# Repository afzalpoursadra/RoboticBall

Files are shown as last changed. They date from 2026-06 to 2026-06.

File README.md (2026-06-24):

# Robotic Ball

An open-source robotic ball platform.

---

## Overview

Robotic Ball is a compact robotics platform that integrates custom mechanical design, embedded electronics, firmware, and a mobile application.
The repository also includes the Gyrobit control UI and release workflow for desktop and Android builds.

The project was developed as a multidisciplinary engineering project involving:

* Mobile Application Development
* Mechanical Design
* PCB Design
* Embedded Programming

---

## Assembly Animation

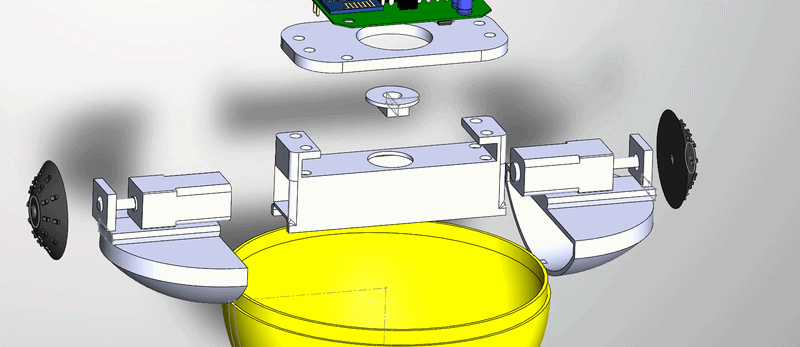
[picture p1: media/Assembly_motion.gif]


---

## Control UI

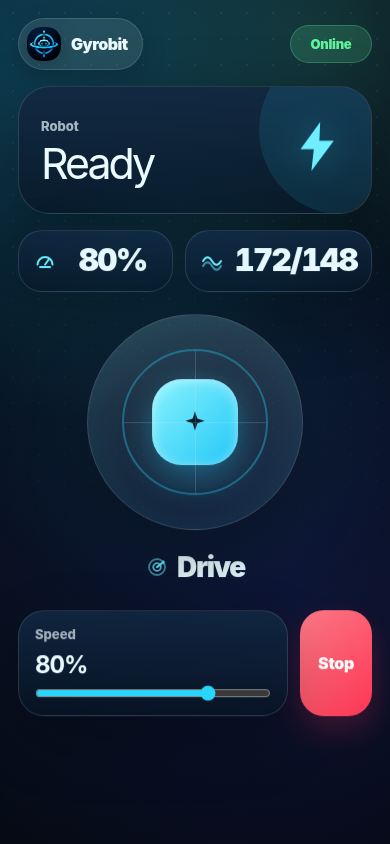
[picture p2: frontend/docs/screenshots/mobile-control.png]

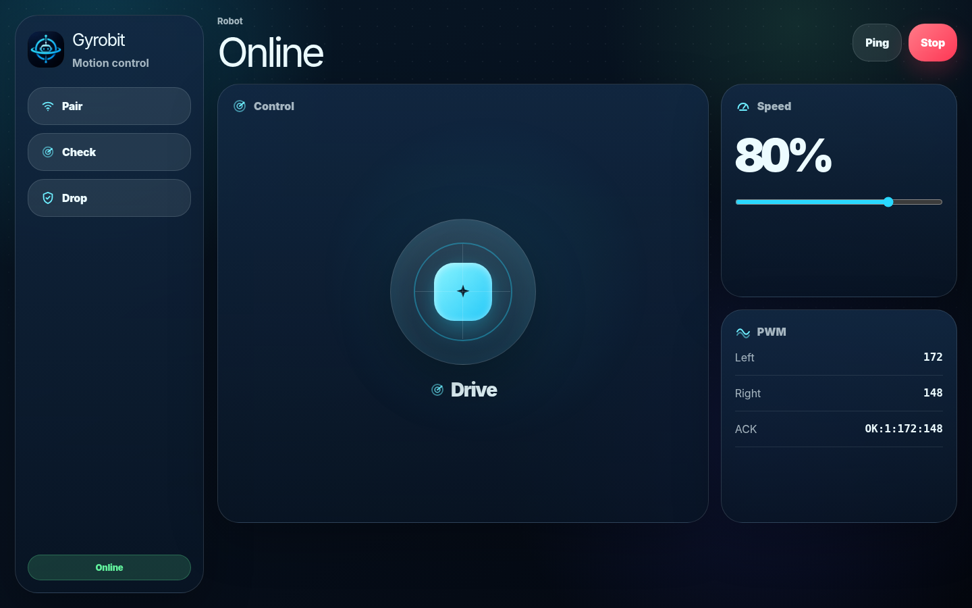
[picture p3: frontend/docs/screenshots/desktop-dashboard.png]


---

### Final Assembly

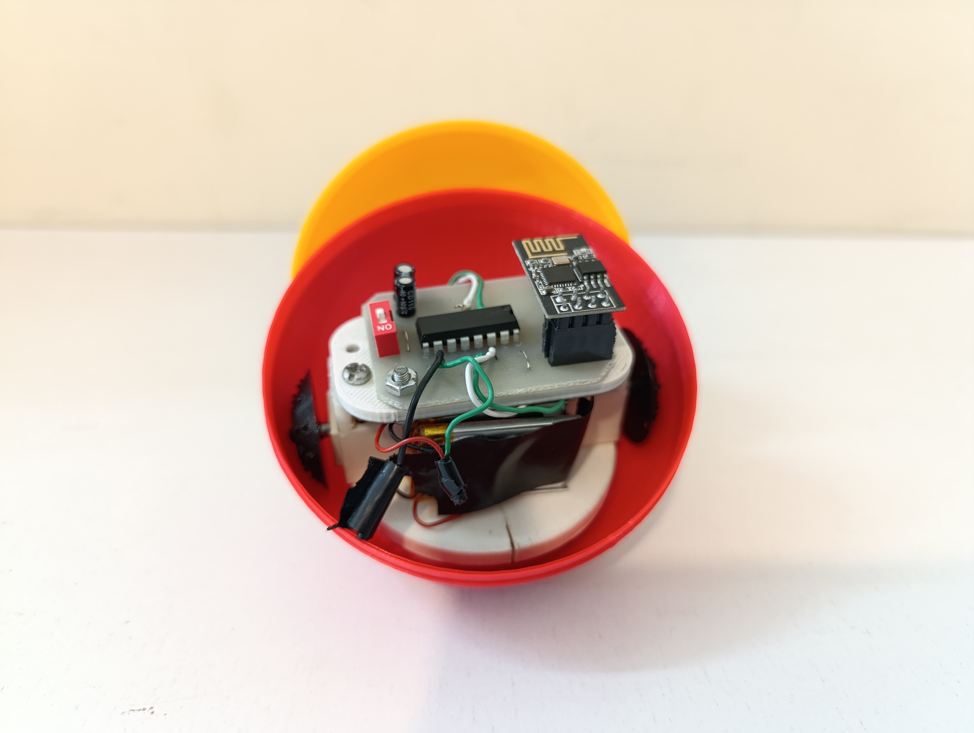
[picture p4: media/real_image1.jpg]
 
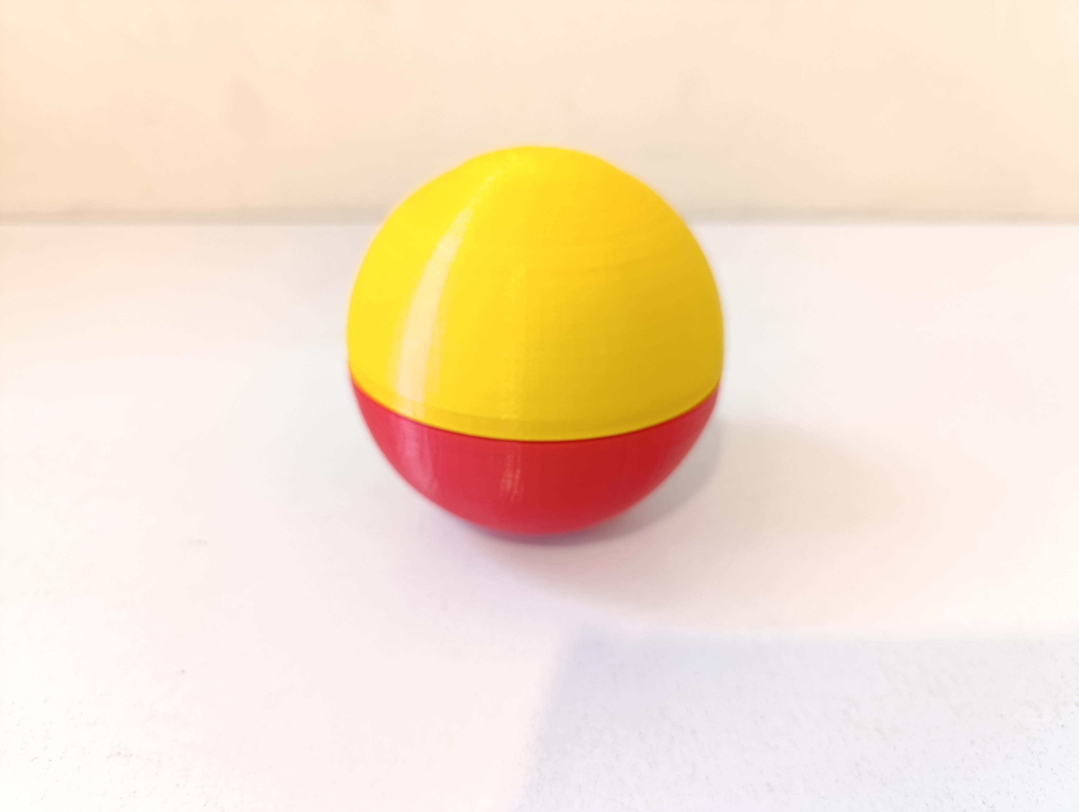
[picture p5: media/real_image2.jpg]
 

---
## Assembly tips

Parts such as the cap and motor holder should be glued together using adhesive.

To charge the batteries, the 2S BMS should be externally attached to the main body.

Then you're ready to go.

---

## License

This project is released under the MIT License.

See the LICENSE file for details.

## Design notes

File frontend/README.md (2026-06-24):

# Gyrobit

Minimal Tauri robot controller for ESP8266 SoftAP robots.

## Preview

### Motion

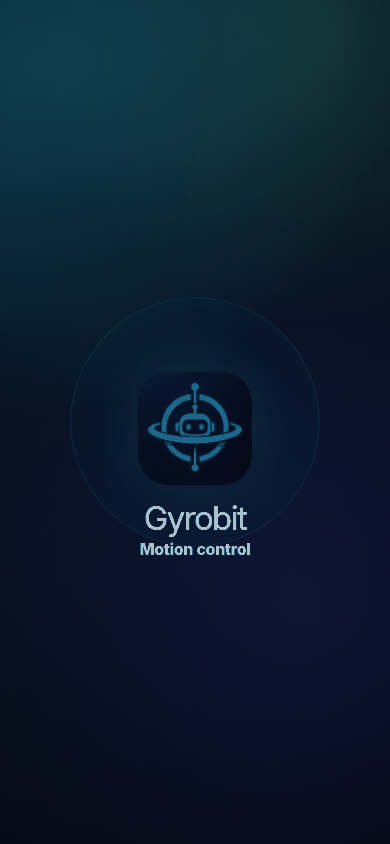
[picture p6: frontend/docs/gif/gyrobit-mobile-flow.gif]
Gyrobit mobile flow


### Pair sheet

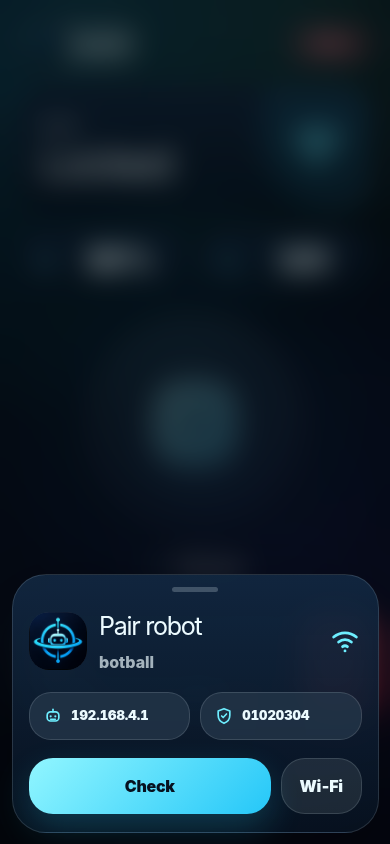
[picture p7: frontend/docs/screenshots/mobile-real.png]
Gyrobit mobile pair


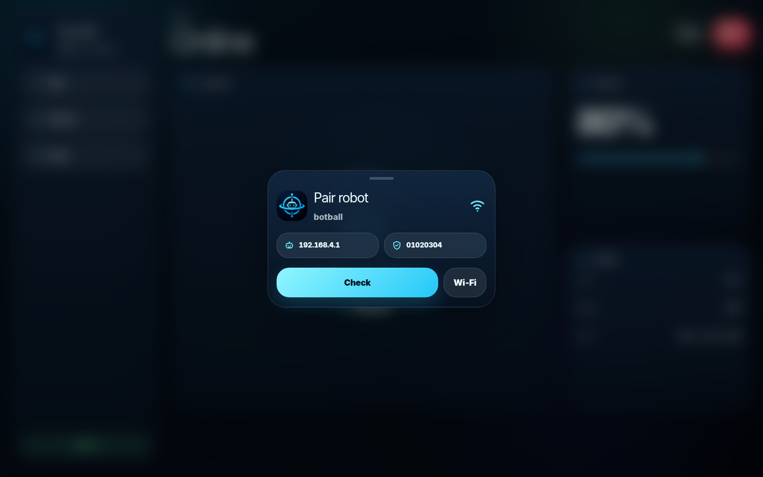
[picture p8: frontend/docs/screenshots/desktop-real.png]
Gyrobit desktop pair


### Control UI

Gyrobit mobile control

Gyrobit desktop dashboard

## Run

```bash
npm install
npm run tauri:dev
```

## Build

```bash
npm run build
npm run tauri:build
```

## Robot link

```txt
SSID: botball
PASS: 01020304
UDP: 192.168.4.1:4210
Payload: J,throttle,steer,speedLimit
ACK: OK:cmd:leftPwm:rightPwm
```

## Features
- Mobile: splash, pair sheet, rounded joystick control.
- Desktop: left panel, dashboard, telemetry cards.
- Wi‑Fi is user-managed; app checks robot by UDP ACK.
- Control payload: `J,throttle,steer,speedLimit`.
- Locked controls until ACK; emergency stop sends stop.
- Firmware: PWM speed, soft turns, failsafe, ACK.

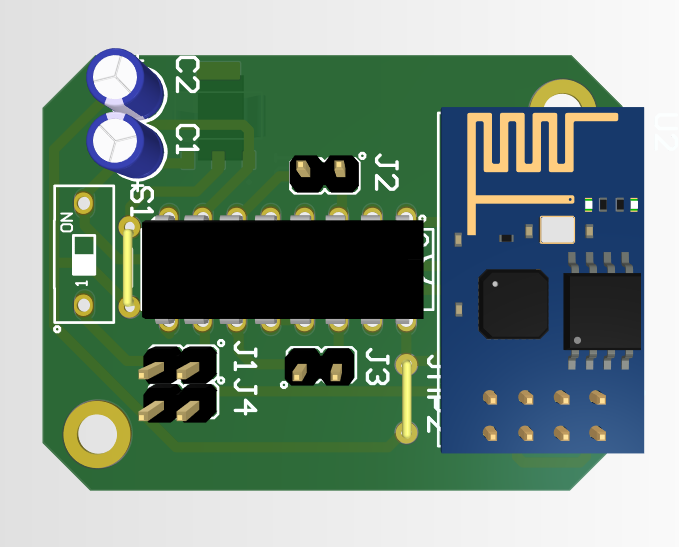
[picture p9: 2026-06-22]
media/PCB.png

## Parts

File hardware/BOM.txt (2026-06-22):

Esp8266_01                      1x

Type of TTL like "CP2102"       1x

l293D IC                        1x

Cap 10uf 25v 4mm                2x

AMS1117-3.3 Smd                 1x 

Bolt M3 10mm                    6x

Nut M3                          2x

DIP switch 1 position           1x

Resistor 4.7k                   2x

wire                           

Header 2*4 used for ESP8266_01  1x

BMS 2S                          1x

Motor N20                       2x

402030 Battery                  2x

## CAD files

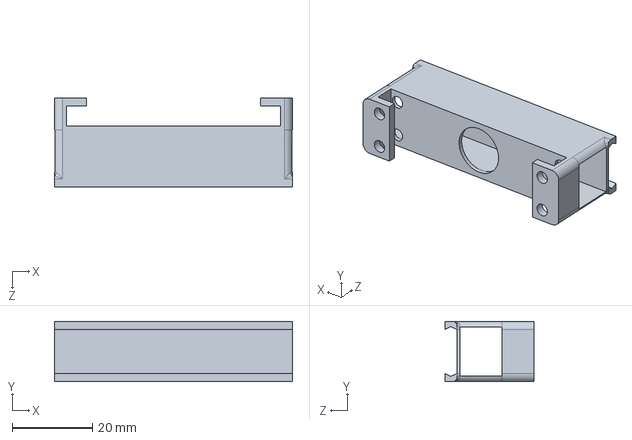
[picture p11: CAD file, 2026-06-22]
mechanical/solidworks/Body_main.SLDPRT
59.4 x 15.0 x 22.3 mm

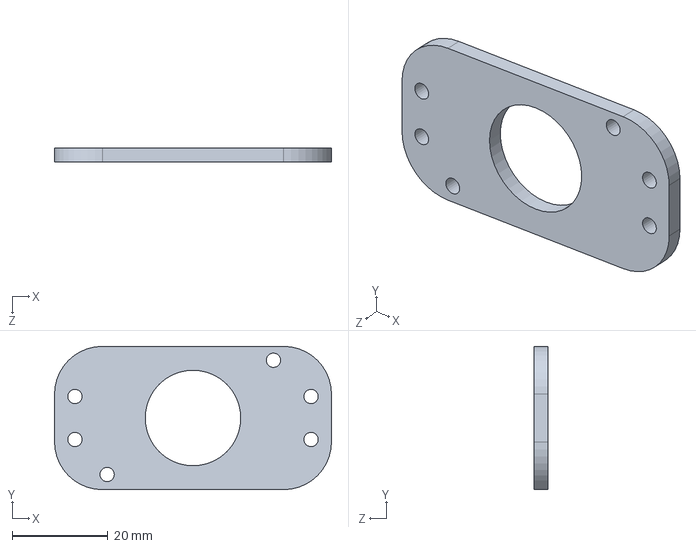
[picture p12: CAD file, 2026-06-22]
mechanical/solidworks/pcb_holder.SLDPRT
58.0 x 30.0 x 3.00 mm

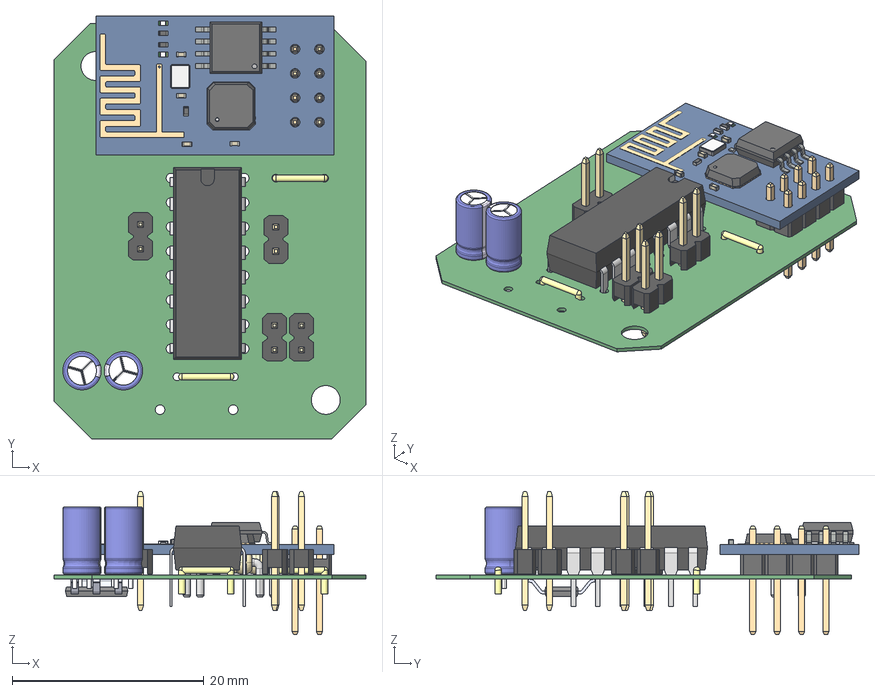
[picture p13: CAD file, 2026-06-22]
mechanical/solidworks/Step_pcb/PCB1.step
32.5 x 44.1 x 14.9 mm
pin_header_aw140-eg-g02a x 4
Resistor Zero x 2
CircuitWorks-DIP 16 IC
User Library-Wi07C
User Library-Cap electrolitic radial 4x7_Case x 2
User Library-Cap electrolitic radial 4x7_Minus x 2
User Library-Cap electrolitic radial 4x7_Top x 2
User Library-Cap electrolitic radial 4x7_Pins x 2
User Library-Cap electrolitic radial 4x7_Bottom x 2

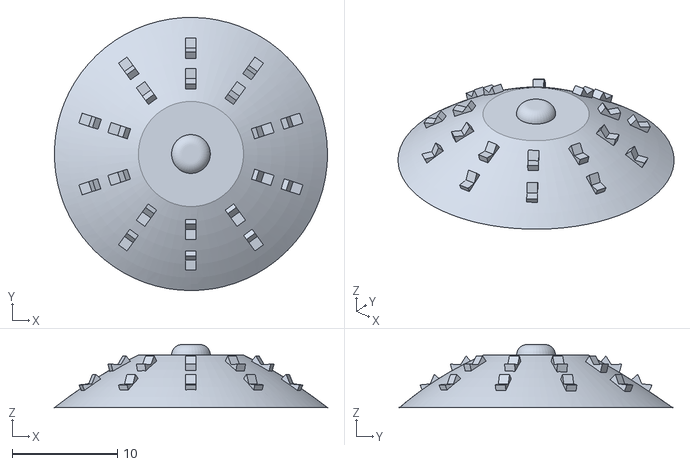
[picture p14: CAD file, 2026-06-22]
mechanical/stl/wheel.STL
26.0 x 26.0 x 6.00

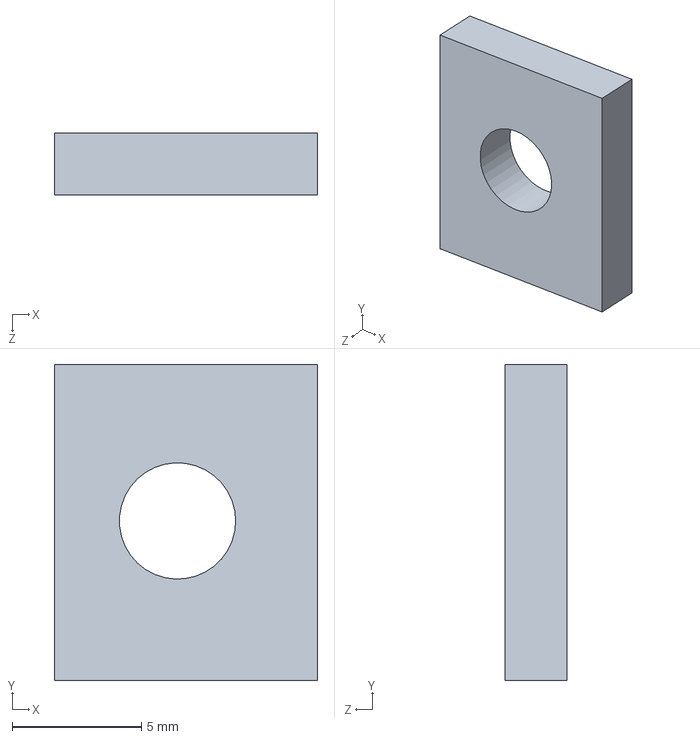
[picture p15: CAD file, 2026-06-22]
mechanical/solidworks/motor_holder_2.SLDPRT
10.2 x 12.2 x 2.40 mm

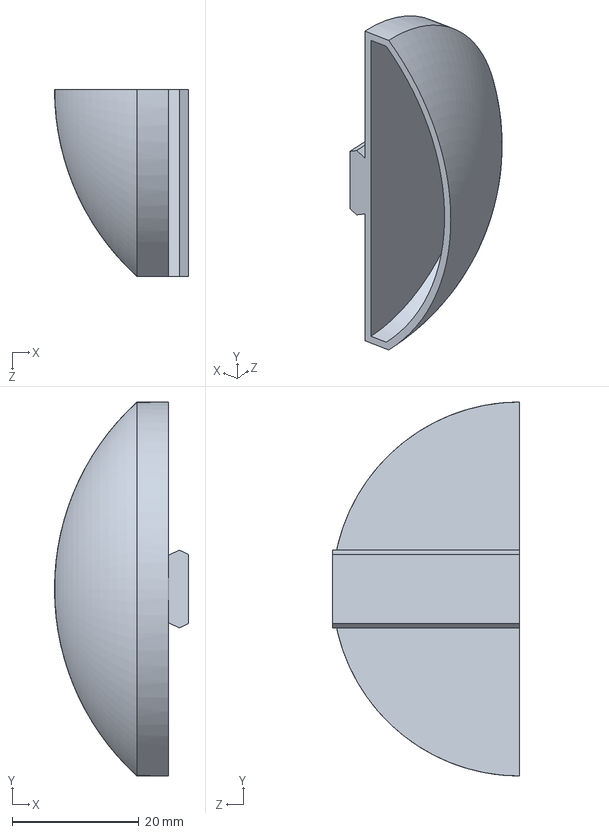
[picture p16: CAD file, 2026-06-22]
mechanical/solidworks/anchor_p2.SLDPRT
21.1 x 59.0 x 29.5 mm

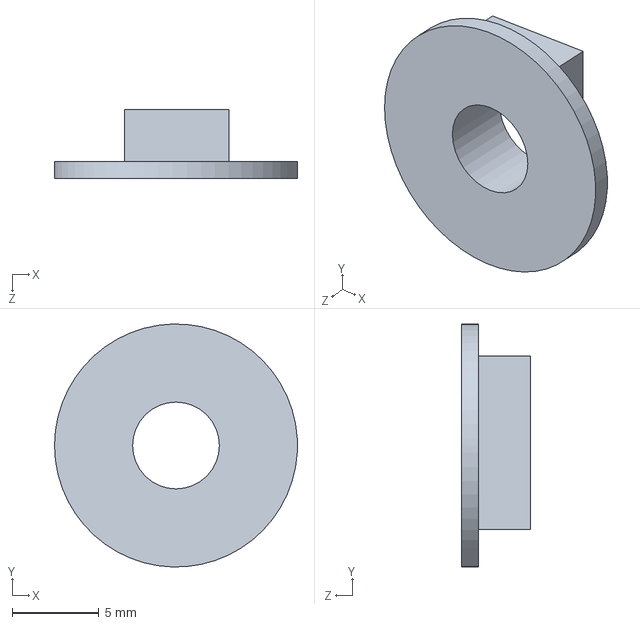
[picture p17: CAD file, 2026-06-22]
mechanical/solidworks/cap.SLDPRT
14.0 x 14.0 x 4.00 mm

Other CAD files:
mechanical/solidworks/wheel_1.SLDPRT
mechanical/solidworks/motor_holder_1.SLDPRT
mechanical/solidworks/wheel_2.SLDPRT
mechanical/solidworks/anchor_p1.SLDPRT
mechanical/stl/Body_main.STL
mechanical/stl/anchor_p1.STL
mechanical/stl/anchor_p2.STL
mechanical/stl/cap.STL
mechanical/stl/motor_holder_1.STL
mechanical/stl/motor_holder_2.STL
mechanical/stl/pcb_holder.STL

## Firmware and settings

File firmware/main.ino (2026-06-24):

#include <ESP8266WiFi.h> 
#include <WiFiUdp.h>
#include <cstring>
#include <stdio.h>

const int left = 2;  
const int right = 0;  

const char *ssidSTA = "botball";
const char *passwordSTA = "01020304";

WiFiUDP udp;
const char *udpAddress = "192.168.4.1"; 
const int udpPort = 4210;
char incomingPacket[255];

int input_switch = 3;
int i = 0;
int result_data = 0;
int result = 0;

unsigned long lastPacketTime = 0;
const unsigned long failsafeTimeout = 500;

// ===== Network Config ===== //

IPAddress ip(192, 168, 4, 1);
IPAddress gateway(192, 168, 4, 1);
IPAddress subnet(255, 255, 255, 0);

// ===== PWM Config ===== //

const int pwmRange = 255;
const int pwmFrequency = 1000;
const int defaultSpeed = 200;
const int minSpeed = 0;
const int maxSpeed = 255;
const int turnInnerPercent = 15;

// ===== Motion State ===== //

int commandSpeed = defaultSpeed;

int targetLeftPwm = 0;
int targetRightPwm = 0;

int currentLeftPwm = 0;
int currentRightPwm = 0;

const int rampStep = 12;
const unsigned long rampInterval = 15;
unsigned long lastRampTime = 0;

const int joystickDeadZone = 12;

unsigned long lastPrintTime = 0;
const unsigned long printInterval = 120;

void setup() {
  pinMode(left, OUTPUT);
  pinMode(right, OUTPUT);
// digitalWrite(left, LOW);
//digitalWrite(right, LOW);

  analogWriteRange(pwmRange);
  analogWriteFreq(pwmFrequency);

  stop_motors();

  Serial.begin(115200); 

  WiFi.mode(WIFI_AP);
  WiFi.softAPConfig(ip, gateway, subnet);
  //WiFi.softAPConfig(udpAddress, gateway, subnet);
  WiFi.softAP(ssidSTA, passwordSTA);

  Serial.println("Access Point started");
  Serial.print("IP address: ");
  Serial.println(WiFi.softAPIP()); 

  udp.begin(udpPort);

  lastPacketTime = millis();
}

// the loop function runs over and over again forever
void loop() {
  get_data();

  if (millis() - lastPacketTime > failsafeTimeout) {
    result = 0;
    set_target_pwm(0, 0);
  }

  update_motors();

  if (millis() - lastPrintTime > printInterval) {
    Serial.print("CMD: ");
    Serial.print(result);
    Serial.print(" | L: ");
    Serial.print(currentLeftPwm);
    Serial.print(" | R: ");
    Serial.println(currentRightPwm);
    lastPrintTime = millis();
  }
}

void get_data(){
    incomingPacket[0] = '\0';

    int packetSize = udp.parsePacket(); 

    if (packetSize) {
      int len = udp.read(incomingPacket, sizeof(incomingPacket) - 1);

      if (len > 0) {
        incomingPacket[len] = 0;
      }

      Serial.printf("Received packet: %s\n", incomingPacket); 

      // ===== Command Parser ===== //

      bool ok = parse_packet(incomingPacket);

      if (ok) {
        lastPacketTime = millis();
        send_ack("OK");
      } else {
        result = 0;
        set_target_pwm(0, 0);
        send_ack("ERR");
      }
    }
}

bool parse_packet(char *packet) {
  char *first = strtok(packet, ",");

  if (first == NULL) {
    return false;
  }

  if (strcmp(first, "J") == 0 || strcmp(first, "j") == 0) {
    return parse_joystick_packet();
  }

  int cmd = atoi(first);

  char *speedToken = strtok(NULL, ",");

  int speed = defaultSpeed;

  if (speedToken != NULL) {
    speed = atoi(speedToken);
  }

  speed = constrain(speed, minSpeed, maxSpeed);

  if (cmd < 0 || cmd > 3) {
    return false;
  }

  result = cmd;
  commandSpeed = speed;
  apply_command(result, commandSpeed);

  return true;
}

bool parse_joystick_packet() {
  char *throttleToken = strtok(NULL, ",");
  char *steerToken = strtok(NULL, ",");
  char *limitToken = strtok(NULL, ",");

  if (throttleToken == NULL || steerToken == NULL) {
    return false;
  }

  int throttle = atoi(throttleToken);
  int steer = atoi(steerToken);
  int speedLimit = 100;

  if (limitToken != NULL) {
    speedLimit = atoi(limitToken);
  }

  throttle = constrain(throttle, -100, 100);
  steer = constrain(steer, -100, 100);
  speedLimit = constrain(speedLimit, 0, 100);

  apply_joystick(throttle, steer, speedLimit);

  return true;
}

void apply_command(int cmd, int speed) {
  switch(cmd){ 
      case 0:
      //get_data();
          set_target_pwm(0, 0);
        break;

      case 1:
      //get_data();
          set_target_pwm(speed, speed);
        break; 

      case 2:
      //get_data();
          set_soft_turn_left(speed);
        break; 

      case 3:
      //get_data();
          set_soft_turn_right(speed);
        break;

      default:
          set_target_pwm(0, 0);
        break;
  }
}

void apply_joystick(int throttle, int steer, int speedLimit) {
  if (abs(throttle) < joystickDeadZone && abs(steer) < joystickDeadZone) {
    result = 0;
    set_target_pwm(0, 0);
    return;
  }

  if (throttle < -joystickDeadZone) {
    result = 0;
    set_target_pwm(0, 0);
    return;
  }

  int limitedMax = map(speedLimit, 0, 100, 0, maxSpeed);
  int speed = map(abs(throttle), 0, 100, 0, limitedMax);

  speed = constrain(speed, minSpeed, maxSpeed);

  if (speed == 0 && abs(steer) >= joystickDeadZone) {
    speed = map(abs(steer), 0, 100, 0, limitedMax);
  }

  if (abs(steer) < joystickDeadZone) {
    result = 1;
    set_target_pwm(speed, speed);
    return;
  }

  int steerAmount = constrain(abs(steer), 0, 100);
  int innerPwm = map(steerAmount, 0, 100, speed, get_turn_inner_pwm(speed));

  if (steer < 0) {
    result = 2;
    set_target_pwm(speed, innerPwm);
  } else {
    result = 3;
    set_target_pwm(innerPwm, speed);
  }
}

void set_soft_turn_left(int speed) {
  int innerPwm = get_turn_inner_pwm(speed);
  set_target_pwm(speed, innerPwm);
}

void set_soft_turn_right(int speed) {
  int innerPwm = get_turn_inner_pwm(speed);
  set_target_pwm(innerPwm, speed);
}

int get_turn_inner_pwm(int speed) {
  int innerPwm = (speed * turnInnerPercent) / 100;
  return constrain(innerPwm, 0, speed);
}

void set_target_pwm(int leftPwm, int rightPwm) {
  targetLeftPwm = constrain(leftPwm, minSpeed, maxSpeed);
  targetRightPwm = constrain(rightPwm, minSpeed, maxSpeed);
}

void update_motors() {
  if (millis() - lastRampTime < rampInterval) {
    return;
  }

  currentLeftPwm = ramp_value(currentLeftPwm, targetLeftPwm);
  currentRightPwm = ramp_value(currentRightPwm, targetRightPwm);

  analogWrite(left, currentLeftPwm);
  analogWrite(right, currentRightPwm);

  lastRampTime = millis();
}

int ramp_value(int currentValue, int targetValue) {
  if (currentValue < targetValue) {
    currentValue += rampStep;

    if (currentValue > targetValue) {
      currentValue = targetValue;
    }
  } else if (currentValue > targetValue) {
    currentValue -= rampStep;

    if (currentValue < targetValue) {
      currentValue = targetValue;
    }
  }

  return currentValue;
}

void send_ack(const char *message) {
  udp.beginPacket(udp.remoteIP(), udp.remotePort());
  udp.print(message);
  udp.print(":");
  udp.print(result);
  udp.print(":");
  udp.print(currentLeftPwm);
  udp.print(":");
  udp.print(currentRightPwm);
  udp.endPacket();
}

void stop_motors() {
  targetLeftPwm = 0;
  targetRightPwm = 0;
  currentLeftPwm = 0;
  currentRightPwm = 0;

  analogWrite(left, 0);
  analogWrite(right, 0);
}

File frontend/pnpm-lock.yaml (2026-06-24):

lockfileVersion: '9.0'

settings:
  autoInstallPeers: true
  excludeLinksFromLockfile: false

importers:

  .:
    dependencies:
      '@tauri-apps/api':
        specifier: ^2.0.0
        version: 2.11.1
      react:
        specifier: ^19.0.0
        version: 19.2.7
      react-dom:
        specifier: ^19.0.0
        version: 19.2.7(react@19.2.7)
      zustand:
        specifier: ^5.0.0
        version: 5.0.14(@types/react@19.2.17)(react@19.2.7)
    devDependencies:
      '@tauri-apps/cli':
        specifier: ^2.0.0
        version: 2.11.3
      '@types/react':
        specifier: ^19.2.17
        version: 19.2.17
      '@types/react-dom':
        specifier: ^19.2.3
        version: 19.2.3(@types/react@19.2.17)
      '@vitejs/plugin-react':
        specifier: ^4.3.4
        version: 4.7.0(vite@6.4.3(jiti@1.21.7))
      autoprefixer:
        specifier: ^10.4.20
        version: 10.5.1(postcss@8.5.15)
      postcss:
        specifier: ^8.4.49
        version: 8.5.15
      tailwindcss:
        specifier: ^3.4.17
        version: 3.4.19
      typescript:
        specifier: ~5.7.2
        version: 5.7.3
      vite:
        specifier: ^6.0.3
        version: 6.4.3(jiti@1.21.7)

packages:

  '@alloc/quick-lru@5.2.0':
    resolution: {integrity: sha512-UrcABB+4bUrFABwbluTIBErXwvbsU/V7TZWfmbgJfbkwiBuziS9gxdODUyuiecfdGQ85jglMW6juS3+z5TsKLw==}
    engines: {node: '>=10'}

  '@babel/code-frame@7.29.7':
    resolution: {integrity: sha512-Aup7aUOfpbAUg2ROOJN6Iw5f9DMBlzu0mIkm/malLQFN/YQgO48wCj0Kxa3sEHJvPVFg7siR+qRInwXd2qhQKw==}
    engines: {node: '>=6.9.0'}

  '@babel/compat-data@7.29.7':
    resolution: {integrity: sha512-locTkQyKvwIEgBzVrn8693ebc97F2U8ZHjbXwDXJ5Fn2TCpNwTlKcaKLkdHop5c/icOFE7qt7Q9JC5hnKNa6Gg==}
    engines: {node: '>=6.9.0'}

  '@babel/core@7.29.7':
    resolution: {integrity: sha512-RgHBCvtjbOK2gXSNBNIkNoEc9qoVEtau3hj8gEqKQuL3HZAibKarWFEI3Lfm6EYKkLalOh8eSrj9b+ch9H/VBA==}
    engines: {node: '>=6.9.0'}

  '@babel/generator@7.29.7':
    resolution: {integrity: sha512-DkXD5OJQaAQIdZ1bt3UZdEnHAn9Imd3IVBdX03UFe+ony9Ojw5pzr9YVKGDY1jt+Gcn/FnGkNf8r+Vj5NOJWtQ==}
    engines: {node: '>=6.9.0'}

  '@babel/helper-compilation-targets@7.29.7':
    resolution: {integrity: sha512-wem6WaBj4NaVYVdNhLPPVacES6ZJ+KBBfSkTMD3YZxbP3rm3Di85tJU5ljaUNhaOynt+Aj0xruhYuzQBt8n71g==}
    engines: {node: '>=6.9.0'}

  '@babel/helper-globals@7.29.7':
    resolution: {integrity: sha512-3nQVUAtvkKH9zahfWgw96Jc/uFOmjACE1kQz82E2lqWmHBgjzbNlsC22nuQTfahmWeQtTq5nQ/4Nnd2A1wj4zA==}
    engines: {node: '>=6.9.0'}

  '@babel/helper-module-imports@7.29.7':
    resolution: {integrity: sha512-ejHwrQQYcm9xnTivShn2IDOlIzInN34AXskvq9QicvCtEzq1Vzclu/tKF8Jq1Cg8JG2GL6/EmjgsCT7lXepE3g==}
    engines: {node: '>=6.9.0'}

  '@babel/helper-module-transforms@7.29.7':
    resolution: {integrity: sha512-UPUVSyXbOh627KiCIGQSgwWzGeBKLkaJ9PJEdrngIwMSzxLR4jS4+f1f1jb7VzBbg8nFLaYotvVPFCTqdrmTAg==}
    engines: {node: '>=6.9.0'}
    peerDependencies:
      '@babel/core': ^7.0.0

  '@babel/helper-plugin-utils@7.29.7':
    resolution: {integrity: sha512-G7sHYigPY17oO5SYWnfD/0MTBwVR781S/JI643e/JhUYgVgWE/61SoW3NH9KWUKyKq5LVh3npif99Wkt6j86Jw==}
    engines: {node: '>=6.9.0'}

  '@babel/helper-string-parser@7.29.7':
    resolution: {integrity: sha512-Pb5ijPrZ89GDH8223L4UP8i6QApWxs04RbPQJTeWDV0/keR2E36MeKnyr6LYmUUvqRRI+Iv87SuF1W6ErINzYw==}
    engines: {node: '>=6.9.0'}

  '@babel/helper-validator-identifier@7.29.7':
    resolution: {integrity: sha512-qehxGkRj55h/ff8EMaJ+cYhyaKlHIxqYDn682wQD7RNp9UujOQsHog2uS0r2vzr4pW+sXf90NeeayjcNaX3fFg==}
    engines: {node: '>=6.9.0'}

  '@babel/helper-validator-option@7.29.7':
    resolution: {integrity: sha512-N9ZErrD+yW5geCDtBqnOoxmR8+tNKiGuxKlDpuJxfsqpa2dFcexaziGAE/qoHLiDDreVNMupxGmSoNlyvsA3gw==}
    engines: {node: '>=6.9.0'}

  '@babel/helpers@7.29.7':
    resolution: {integrity: sha512-1k2lAGRMfHTcwuNYcCNUmaUffmQv8KWMfh2iJUUeRlwlwH4FdNG7mfPI10NPfLHJFThE4Tyr4mv7kTNZOiPuBg==}
    engines: {node: '>=6.9.0'}

  '@babel/parser@7.29.7':
    resolution: {integrity: sha512-hnORnjP/1P/zFEndoeX+n+t1RwWRJiJpM/jO7FW32Kn9r5+sJB2JWOdYo4L6k78j15eCwY3Gm/7364B1EMwtNg==}
    engines: {node: '>=6.0.0'}
    hasBin: true

  '@babel/plugin-transform-react-jsx-self@7.29.7':
    resolution: {integrity: sha512-TL0hMc9xzy86VD31nUiwzd5otRAcyEPcsegCxolO0PvcXuH1v0kECe/UIznYFihpkvU5wg/jk4v0TTEFfm53fw==}
    engines: {node: '>=6.9.0'}
    peerDependencies:
      '@babel/core': ^7.0.0-0

  '@babel/plugin-transform-react-jsx-source@7.29.7':
    resolution: {integrity: sha512-06IyK09H3wi4cGbhDBwp5gUGo0IKtnYa8tyTiephirPCK6fbobVGiXMMI5zLQ4aKEYP3wZ3ArU44o+8KMrSG/Q==}
    engines: {node: '>=6.9.0'}
    peerDependencies:
      '@babel/core': ^7.0.0-0

  '@babel/template@7.29.7':
    resolution: {integrity: sha512-puq+Gf35oI24FeN11LkoUQFqv9uwNeWpxXZi/Ji3rRIoKAzKnxRaZ+Gkj0vKS9ZCiTESfng1N9LyOyXvo+m+Gg==}
    engines: {node: '>=6.9.0'}
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

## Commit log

2026-06-22 replace mp4 with gif Assembly
2026-06-24 chore(arduino) remove unused iostream include
2026-06-24 fix(arduino) configure esp8266 softap static ip
    [main.ino]
2026-06-24 feat(arduino) add udp failsafe motor stop
    [main.ino]
2026-06-24 feat(arduino) add udp command validation and ack
2026-06-24 change(arduino) extract motor stop helper
2026-06-24 feat(arduino) add pwm motor speed state
2026-06-24 feat(arduino) add speed and joystick command parser
2026-06-24 change(arduino) drive motors with ramped pwm output
2026-06-24 change(android) align theme with gyrobit branding
2026-06-24 fix(android) complete android apk build
    [lib.rs]
2026-06-24 change(readme) polish overview and assembly notes
